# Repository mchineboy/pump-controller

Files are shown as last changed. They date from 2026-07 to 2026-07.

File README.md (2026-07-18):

# Fluid Dispensing Controller

Open-source ESP32 firmware and local web UI for **precision fluid dispensing**
with stepper-driven peristaltic pump(s). Suitable for lab dosing, hydroponics,
coolant metering, photography chemistry, laundry soap, and other applications
where calibrated volume delivery matters.

**Board:** ELEGOO ESP32 Dev Board (ESP32-WROOM-32, CP2102, USB-C)  
**Framework:** PlatformIO + Arduino  
**UI:** HTML / CSS / vanilla JS served from LittleFS  
**License:** [MIT](LICENSE)

## Hardware credit

The 3D-printable peristaltic pump mechanical design is by
**[Maximilian Puschmann](https://www.printables.com/@MaxPuschmann_1657997)**:

- [V2 — Nema 17 Peristaltic Pump on Printables](https://www.printables.com/model/1556845-v2-nema-17-peristaltic-pump-water-pump-measuring-p)
- Local author documentation: [docs/hardware/maximilian-puschmann-nema17-peristaltic-pump-v2.pdf](docs/hardware/maximilian-puschmann-nema17-peristaltic-pump-v2.pdf)

This repository provides the controller firmware, electronics integration, and
web UI around that design. See [docs/HARDWARE.md](docs/HARDWARE.md),
[docs/BOM.md](docs/BOM.md), [docs/WIRING.md](docs/WIRING.md), and
[cad/enclosure/](cad/enclosure/) for dry-side enclosure STEP files
([v1 monolithic](cad/enclosure/v1/), [v2 sectional](cad/enclosure/v2/)).

## Features

- DHCP Wi-Fi (credentials in ignored `include/secrets.h`) with soft-AP fallback
- Local web UI: dispense, calibration, profiles, configuration, diagnostics, hardware
  (includes a dynamic color-coded wiring diagram modal)
- Six generic fluid profiles (Fluid 1–6), renameable, with independent calibration
- **Multi-pump:** 1–3 fluid paths (`pump_count` in Configuration; default **1**)
  - Each profile binds to `pump_1`, `pump_2`, or `pump_3`
  - Sequential motion only (one path at a time); ESTOP stops all paths
  - Shared TMC2209 UART bus (addresses `0b00` / `0b01` / `0b10`)
- STEP/DIR/ENABLE motor control per path (see pin tables below)
- Timed calibration with multi-sample averaging and history
- Configurable speed / acceleration (speed change clears calibration)
- Volume dispense via `steps_per_ml`
- Optional sensors: load cell, temperature, pulse flow; optional closed-loop feedback
- Optional basic auth, event log, config export/import, Factory Reset
- Safe boot: drivers disabled, valves closed, no operation resume
- Durable config in **NVS** (survives firmware and LittleFS uploads)

## Quick start

1. Copy `include/secrets.example.h` to `include/secrets.h` and set Wi-Fi credentials.
2. Connect the board with a data-capable USB-C cable.
3. Build and upload:

```bash
pio run -t upload
pio run -t uploadfs
```

4. Open the DHCP address printed on serial (or fallback AP `PumpController` /
   `pumpsetup` at http://192.168.4.1).

Optional web auth uses `Secrets::kWebUsername` / `kWebPassword` when enabled on
the Configuration page.

### Enabling a second or third pump

1. Wire the extra TMC2209 + NEMA 17 using the pump 2 / pump 3 pins below.
2. Strap UART addresses (`0b01`, `0b10`) on the shared RX/TX lines.
3. In **Configuration → Pumps**, set **Number of installed pumps** to 2 or 3.
4. On **Profiles**, bind each fluid to the correct pump path, then calibrate.

Full detail: [docs/HARDWARE.md](docs/HARDWARE.md#multi-pump--additional-fluid-paths-optional)
and [docs/WIRING.md](docs/WIRING.md).

## Default pins

See [docs/WIRING.md](docs/WIRING.md) for power distribution, TMC2209 connections,
and optional ESTOP / valve / UART / reservoir / sensor wiring.

### Pump 1 (always present)

| Signal | GPIO |
|---|---|
| STEP | 26 |
| DIR | 27 |
| ENABLE | 25 (active low) |
| VALVE  | 33 (optional, disabled by default) |

### Pump 2 (optional, `pump_count` ≥ 2)

| Signal | GPIO |
|---|---|
| STEP | 5 |
| DIR | 13 |
| ENABLE | 14 (active low) |
| VALVE  | 21 (optional) |
| TMC UART address | `0b01` |

### Pump 3 (optional, `pump_count` ≥ 3)

| Signal | GPIO |
|---|---|
| STEP | 22 |
| DIR | 15 (strapping — keep quiet at boot) |
| ENABLE | 2 (active low) |
| VALVE  | 12 (optional; strapping) |
| TMC UART address | `0b10` |

### Shared / optional

| Signal | GPIO |
|---|---|
| ESTOP  | 32 (optional, disabled by default) |
| TMC RX | 16 (optional UART, shared by all drivers) |
| TMC TX | 17 (optional UART, shared by all drivers) |
| RESERVOIR | 34 (optional empty sense) |
| HX711 DT / SCK | 19 / 18 (optional load cell) |
| TEMP | 23 (optional DS18B20) |
| FLOW | 4 (optional pulse) |

## Project layout

```text
src/           firmware
include/       headers
data/          LittleFS web assets
cad/           enclosure STEP / FreeCAD source
docs/          design notes, BOM, hardware credit, wiring
docs/hardware/ pump author documentation (PDF)
.cursor/rules/ agent workflow and documentation rules
```

## Contributing

See [CONTRIBUTING.md](CONTRIBUTING.md) for build setup, scope, and pull request
expectations. Product changes that affect pins, features, storage, or APIs must
update the matching docs in the same PR.

## Notes

- Calibration and hardware settings live in **NVS** and survive `upload` /
  `uploadfs` / OTA. Clear them only via Configuration **Factory Reset** (or a full
  `erase_flash`).
- `pio run -t uploadfs` rewrites LittleFS (web UI). Event logs and on-device
  calibration *history files* on LittleFS are lost; profile calibrations in NVS
  are not.
- ENABLE polarity assumes a typical TMC2209 active-low enable.
- Valve, ESTOP, sensors, and multi-pump paths are off/inactive until enabled in
  Configuration (`pump_count` defaults to 1).
- Size the 12 V supply for **one** NEMA 17 at a time unless you validate
  concurrent motor load (firmware does not run paths concurrently).

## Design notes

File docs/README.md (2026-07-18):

# Documentation

Index of project documentation for the ESP32 fluid dispensing controller.

## Contents

| Document | Description |
|---|---|
| [DESIGN.md](DESIGN.md) | Software design summary: calibration/dispense rules, Configuration vs Diagnostics UI responsibilities, NVS storage, multi-pump model, safety, and phased feature status. |
| [HARDWARE.md](HARDWARE.md) | Mechanical pump credit, electronics overview, optional sensors, **multi-pump pin map** (1–3 paths), safety notes, enclosure CAD links. |
| [BOM.md](BOM.md) | Bill of materials for a complete build; notes how motor/driver/pump parts scale with pump count. |
| [WIRING.md](WIRING.md) | Default ESP32 / TMC2209 pin map for pump 1–3, power distribution, UART addressing, and pre-power safety checks. |
| [hardware/maximilian-puschmann-nema17-peristaltic-pump-v2.pdf](hardware/maximilian-puschmann-nema17-peristaltic-pump-v2.pdf) | Local copy of the upstream peristaltic pump author documentation (print/assembly). |

Dry-side enclosure STEP models live under [`cad/enclosure/`](../cad/enclosure/) (not under `docs/`). The v2 enclosure assumes multi-pump layouts; firmware supports up to **three** sequential paths (`pump_count` 1–3).

**Quick links:** [Multi-pump (HARDWARE)](HARDWARE.md#multi-pump--additional-fluid-paths-optional) · [Pin summary (WIRING)](WIRING.md#pin-summary) · [Flash survival (DESIGN)](DESIGN.md#durable-storage--flash-survival)

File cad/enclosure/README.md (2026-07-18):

# Dry-side electronics enclosure

Two designs share this folder. Prefer **v2** for new builds.

| Version | Layout | When to use |
|---|---|---|
| **[v1](v1/)** — monolithic | Single 120×90 mm box + lid | Simple 1-driver prototypes |
| **[v2](v2/)** — sectional | Controller + driver modules + endcap | 1–6 pumps; each printable part ≤ 200 mm |

Generators write **only** into their own directory and do not delete the other
version’s exports.

## Regenerate

```bash
# v1 monolithic
/Applications/FreeCAD.app/Contents/Resources/bin/freecadcmd \
  cad/enclosure/v1/generate_enclosure_v1.py

# v2 sectional
/Applications/FreeCAD.app/Contents/Resources/bin/freecadcmd \
  cad/enclosure/v2/generate_enclosure_v2.py
```

Pumps do not mount to these enclosures. Keep liquid plumbing physically
separated from the dry-side box. See [docs/HARDWARE.md](../../docs/HARDWARE.md)
and [docs/WIRING.md](../../docs/WIRING.md).

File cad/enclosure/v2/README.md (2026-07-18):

# Enclosure v2 — sectional

Modular dry-side box. Each printable part is ≤ **200 mm** in its longest
dimension. Larger pump counts are built by joining sections.

## Modules

| Part | Role |
|---|---|
| `controller_base/lid` | Half-size breadboard bay, buck bay, barrel jack, USB slot, optional 40 mm fan on lid |
| `driver_x1_base/lid` | One generic TMC2209 + breakout bay |
| `driver_x2_base/lid` | Two generic driver bays |
| `endcap_base/lid` | Three Ø10 mm cable / grommet exits toward the wet side |

Mating: +X tongue into the next module’s −X groove, plus M3 clamp holes at the
joint walls.

## Assembly matrix (N pumps)

Prefer `driver_x2`, remainder `driver_x1`, then always finish with `endcap`:

| N | Sections after controller |
|---|---|
| 1 | x1 + endcap |
| 2 | x2 + endcap |
| 3 | x2 + x1 + endcap |
| 4 | x2 + x2 + endcap |
| 5 | x2 + x2 + x1 + endcap |
| 6 | x2 + x2 + x2 + endcap |

Preview assemblies: `assembly_1pump.step` … `assembly_6pump.step`.

## Design intent

- **Breadboard:** standard half-size 400-point, nominal **82 × 55 × 10 mm**.
- **ESP32** and logic wiring sit on the breadboard.
- **TMC2209** motor VM / coil current uses rated breakout boards in driver bays.
- **Buck converter:** generic ~40 × 20 × 10 mm bay near the barrel jack.
- Concurrent pumps: space for 1–6 drivers; design assumption **up to 3 concurrent**.
- Corner bosses: **M3 heat-set insert** pilots (Ø4.0 mm).
- Controller lid: optional **40 mm fan** (32 mm screw pitch).

## Envelope (per module)

Widths and heights are shared: **95 × ~53 mm** (base 50 + lid 3). Lengths are
printed by the generator at run time.

## Files

| File | Description |
|---|---|
| `generate_enclosure_v2.py` | Parametric generator |
| `enclosure_sectional.FCStd` | FreeCAD document |
| `controller_*`, `driver_*`, `endcap_*` | Module STEP exports |
| `assembly_*pump.step` | Preview assemblies |

## Regenerate

```bash
/Applications/FreeCAD.app/Contents/Resources/bin/freecadcmd \
  cad/enclosure/v2/generate_enclosure_v2.py
```

Writes only into `cad/enclosure/v2/` — does not modify [v1](../v1/) exports.

## Print / assembly notes

- PETG recommended.
- Install M3 heat-set inserts in base bosses; M3×8–12 mm lid screws.
- Confirm barrel-jack panel diameter (`BARREL_D`).
- Fit rubber grommets in endcap cable exits.
- Revise `DRIVER_BAY_*` once the exact breakout board is chosen.

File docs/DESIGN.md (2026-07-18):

# Software Design Summary

Source: project software design document (2026-07-18).

## Core decisions

1. **Calibration:** timed dispense (default 1000 ms) → user enters measured mL → store `steps_per_ml`.
2. **Dispense:** `target_steps = volume_ml * steps_per_ml` (step-count based, not wall-clock only).
3. **Speed rule:** calibration speed must equal dispense speed.
4. **Web client:** HTML + CSS + vanilla JS + ES modules + `fetch` + SSE. No React/Vue/etc.
5. **Storage:** Preferences/NVS for settings **and** fluid profiles/calibration;
   LittleFS for web assets, optional calibration history, and event logs.
6. **Safety:** safe boot, no auto-resume after power loss, software stop, optional ESTOP later.

## Implemented

### Phase 1–2
- Six generic fluid profiles (Fluid 1–6), renameable per use case
- Repeated calibration samples with averaging / CV warning (>3%)
- Calibration history per profile
- Configurable speed and acceleration
- Optional local basic auth (`admin` / `secrets.h`)
- Event logging
- Configuration export / import

### Phase 3 (complete)
- Optional valve pre-open / post-close, anti-drip reverse
- TMC2209 UART config + diagnostics
- Physical ESTOP
- Reservoir empty sensor (warn/block/fault)

### Phase 4 (in progress)
Tracked on GitHub milestone **Phase 4**, in design-doc order:
1. Load-cell verification (HX711) — done
2. Temperature monitoring — done
3. Flow sensor — done
4. Closed-loop dispensing — done
5. Multi-pump support — done (up to three paths, sequential motion; `pump_count` default 1)
6. Automated mixing jobs
7. Recipe engine (use-case agnostic)

Product branding is use-case agnostic: **Fluid Dispensing Controller**.

## Multi-pump model

- **Paths:** `pump_1` … `pump_3` (compile-time pins in `Config.h` / `platformio.ini`).
- **Setting:** `GlobalSettings.pumpCount` (NVS), default `1`. Configuration UI sets 1–3.
- **Binding:** each `FluidProfile` has `pump_id`; dispense/calibrate select that path’s STEP/DIR/EN (+ optional valve).
- **Motion:** one global busy operation — no concurrent STEP generation in this cut.
- **TMC UART:** shared RX/TX; per-driver address `0b00` / `0b01` / `0b10`.
- **Safety:** ESTOP and safe-output paths stop/disable **all** configured pumps.

Pin tables and strapping notes: [HARDWARE.md](HARDWARE.md), [WIRING.md](WIRING.md), root [README.md](../README.md).

## Durable storage / flash survival

| Data | Location | Survives `upload` | Survives `uploadfs` | Survives OTA app | Cleared by |
|---|---|---|---|---|---|
| Hardware settings | NVS `pump_settings` | Yes | Yes | Yes | Factory Reset / `erase_flash` |
| Profiles + calibration | NVS `pump_prof` | Yes | Yes | Yes | Factory Reset / `erase_flash` |
| Web UI assets | LittleFS | Yes | Replaced | Yes | `uploadfs` |
| Event log / cal history | LittleFS | Yes | Lost | Yes | `uploadfs` / Factory Reset |

Firmware never erases NVS on boot or upgrade. Explicit **Factory Reset**
(`POST /api/factory-reset` with `{"confirm":"FACTORY_RESET"}`) clears NVS
namespaces and reseeds defaults, then reboots.

## Web UI responsibilities

- **Configuration:** durable device, pump, safety, sensor, feedback, and
  motor-driver settings; scale setup; Factory Reset.
- **Diagnostics:** live hardware readings, fault simulation/acknowledgement,
  flow-session reset, and event log.
- **Hardware:** read-only pin-map reference and a color-coded SVG wiring
  diagram modal driven by the active pump count and enabled options.

Configuration uses outcome-oriented labels and keeps electrical details behind
progressive disclosure. Diagnostics does not mutate durable hardware settings.

## Board

ELEGOO ESP32 Dev Board · ESP32-WROOM-32 · CP2102 · USB-C · PlatformIO `esp32dev`.

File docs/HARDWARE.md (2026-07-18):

# Hardware

## Primary credit — peristaltic pump mechanical design

The printable peristaltic pump (housing, tube-pressure part, lid, and bearing
holder/rotor) is **not** an original design of this repository.

**Primary designer:** [Maximilian Puschmann](https://www.printables.com/@MaxPuschmann_1657997)
**Model:** [V2 — Nema 17 Peristaltic Pump / Water Pump / Measuring Pump](https://www.printables.com/model/1556845-v2-nema-17-peristaltic-pump-water-pump-measuring-p)
**Local copy of the author’s documentation:**
[hardware/maximilian-puschmann-nema17-peristaltic-pump-v2.pdf](hardware/maximilian-puschmann-nema17-peristaltic-pump-v2.pdf)

Download the STEP/STL files and follow print/assembly guidance from the
Printables page. Adjust the bearing-holder fit for your printer before pressing
on 608 bearings.

This project contributes the ESP32 controller firmware, electronics integration,
optional valve path, calibration/dispense software, and local web UI around that
mechanical design.

## Electronics overview

| Role | Part |
|---|---|
| Controller | ESP32 development board (Wi-Fi, USB programming) |
| Motor | STEPPERONLINE NEMA 17 bipolar stepper (1.5 A/phase) |
| Driver | BIGTREETECH TMC2209 V1.3 UART StepStick |
| Motor supply | 12 V regulated DC supply |
| Logic supply | 5 V buck converter feeding ESP32 5V/VIN |

Full part list: [BOM.md](BOM.md).
Wiring diagrams and connection tables: [WIRING.md](WIRING.md).
On the device, open **Hardware → View wiring diagram** (also linked from
**Configuration → Pumps**) for a color-coded SVG of the active pump count and
enabled options.
Dry-side enclosure STEP models: [../cad/enclosure/](../cad/enclosure/)
([v1 monolithic](../cad/enclosure/v1/), [v2 sectional](../cad/enclosure/v2/)).

## Safety notes

- Verify the 5 V buck output with a multimeter before connecting the ESP32.
- Keep liquid plumbing physically separated from electronics.
- Do not drive a piezoelectric valve directly from an ESP32 GPIO; use a matched
  valve driver.
- Place an inline fuse near the 12 V power-entry point when building a permanent
  enclosure.

## Emergency stop (optional)

Default pin: **GPIO 32** (`PUMP_ESTOP_PIN`), active-low with ESP32 internal pull-up.

Recommended wiring:

- Use a normally-open (NO) momentary or maintained ESTOP that connects GPIO 32
  to GND when pressed/latched.
- Keep the switch on a short, dedicated cable; do not share with motor power
  returns in a way that injects noise onto the sense line.
- Enable “Use the wired emergency-stop input” in Configuration before relying on
  the switch. When enabled, ESTOP is polled in the firmware loop (not via HTTP).
- On assert: step pulses stop, valve closes, driver disables, system enters
  fault. Clear the switch, then acknowledge the fault in the UI before starting
  another operation.

## TMC2209 UART (optional)

Default pins: **RX GPIO 16**, **TX GPIO 17** (`PUMP_TMC_RX_PIN` / `PUMP_TMC_TX_PIN`).
Baud: 115200. Driver address: `0b00` (MS1/MS2 low on BIGTREETECH V1.3).

Wiring notes:

- Connect ESP32 TX → TMC PDN_UART (through the board’s UART path; do not leave
  PDN_UART floating if UART mode is intended).
- Connect ESP32 RX ← TMC UART TX / PDN_UART sense path per the StepStick silkscreen.
- Keep STEP/DIR/ENABLE wired regardless; UART only configures current,
  microsteps, and StealthChop. Motion remains STEP/DIR.
- Sense resistor assumed **0.11 Ω** (standard on BTT TMC2209 V1.3).
- Open Configuration → Advanced motor-driver settings, enable UART, and set
  run/hold current and microsteps.
  On miswire or no response, boot continues in STEP/DIR-only mode and logs
  `tmc_uart_warning` / `tmc_uart_no_response`.

When UART is ready, firmware polls `DRV_STATUS` about every 100 ms. Overtemperature
or short-circuit flags raise `motor_driver_fault`, stop motion, and close the valve.
Open-load is only treated as a fault while coils are driven. Acknowledge after the
condition clears (Diagnostics includes a simulate-fault control for testing without
hardware).

## Reservoir level sensor (optional)

Default pin: **GPIO 34** (`PUMP_RESERVOIR_PIN`). This pin is input-only and has no
internal pull-up; use an external pull-up (e.g. 10 kΩ to 3.3 V) with a
normally-open float or optical empty switch to GND for active-low empty.

Recommended wiring:

- Float switch or optical liquid sensor that asserts empty when the reservoir is
  low/dry.
- Default polarity: empty = LOW (Configuration labels this “Sensor connects the
  input to ground when empty”). Invert if your sensor is active-high.
- Policy options: **warn** (status only), **block** (refuse new dispense/calibrate),
  **fault** (also stop an in-progress operation with `reservoir_empty`).
- With the sensor disabled, dispense behavior is unchanged.

## Load cell / HX711 (optional)

Default pins: **DT GPIO 19**, **SCK GPIO 18** (`PUMP_LOADCELL_DT_PIN` /
`PUMP_LOADCELL_SCK_PIN`). Channel A, gain 128.

Recommended parts:

- HX711 amplifier module (5 V or 3.3 V logic-compatible with ESP32 levels)
- Strain-gauge load cell sized for the expected container + fluid mass (e.g.
  1–5 kg for typical beaker verification)

Wiring:

- HX711 DT → GPIO 19, SCK → GPIO 18, VCC/GND per module rating
- Excitation and sense to the load cell per HX711 silkscreen (E+/E−, A+/A−)

Usage:

- Enable and calibrate the scale in Configuration, then set zero with the empty
  vessel on the cell
- Place a known mass and **Calibrate** (stores scale factor + offset in NVS)
- Status shows grams and optional mL via fluid density (g/mL)
- Miswire/timeout does not brick boot; logs `loadcell_warning`
- Does not alter dispense control yet (closed-loop is a later Phase 4 issue)

## Temperature sensor (optional)

Default pin: **GPIO 23** (`PUMP_TEMP_PIN`), 1-Wire **DS18B20**.

Wiring:

- DS18B20 data → GPIO 23 with **4.7 kΩ** pull-up to 3.3 V
- VDD to 3.3 V (or parasite power per datasheet), GND to GND

Usage:

- Enable in Configuration; optional warn-low / warn-high thresholds (°C)
- Status shows live °C; threshold crossings log `temp_threshold` (warn only, no fault)
- Absent sensor does not brick boot (`temp_no_device` / `temp_warning`)

## Flow sensor (optional)

Default pin: **GPIO 4** (`PUMP_FLOW_PIN`), active-low pulse with internal pull-up.

Recommended: hall-effect turbine flow meter with open-collector/NPN pulse output
(common YF-S201-class sensors; set pulses-per-liter from the datasheet K-factor).

Wiring:

- Pulse → GPIO 4, GND shared; supply the sensor at its rated voltage (often 5 V)
  with level-safe signaling to the ESP32

Usage:

- Enable in Configuration and set pulses/liter
- Status shows mL/min and cumulative mL; **Reset cumulative** clears the session
  total (`POST /api/flow/reset`)
- Does not alter dispense control yet (closed-loop is #20)

## Dispense feedback / closed-loop (optional)

Configuration section **Volume accuracy**:

- `open_loop` (default): step-count only
- `verify_after`: run open-loop, then compare load-cell or flow volume to request
- `stop_on_feedback`: stop motor when feedback volume reaches ~98% of request

Source: `auto` (load cell if ready, else flow), `load_cell`, or `flow`. Density
(g/mL) converts load-cell mass to mL. Out-of-tolerance can **warn** or **fault**
(`volume_verification_failed`). Sensor loss during feedback modes raises
`feedback_sensor_lost`.

## Multi-pump / additional fluid paths (optional)

Default is **one path** (`pump_count = 1`), identical to prior single-pump builds.

Set **Number of installed pumps = 2 or 3** in Configuration to activate
additional STEP/DIR/ENABLE paths. Bind each fluid profile to `pump_1`,
`pump_2`, or `pump_3` on the Profiles page.

| Path | STEP | DIR | ENABLE | Optional valve | TMC UART address |
|---|---|-----|---|---|---|
| `pump_1` | GPIO 26 | GPIO 27 | GPIO 25 | GPIO 33 | `0b00` (MS1/MS2 low) |
| `pump_2` | GPIO 5 | GPIO 13 | GPIO 14 | GPIO 21 | `0b01` |
| `pump_3` | GPIO 22 | GPIO 15 | GPIO 2 | GPIO 12 | `0b10` |

All TMC2209 drivers share UART pins RX 16 / TX 17; address via MS1/MS2.
Motion is **sequential**: only one path runs at a time. ESTOP stops all paths.

**Strapping:** GPIO 15 (pump 3 DIR) and GPIO 12 (pump 3 valve) are ESP32 boot
strapping pins. Keep external loads from forcing bad levels at reset; firmware
drives safe idle levels after boot.

See [WIRING.md](WIRING.md) pin summary for the full map.

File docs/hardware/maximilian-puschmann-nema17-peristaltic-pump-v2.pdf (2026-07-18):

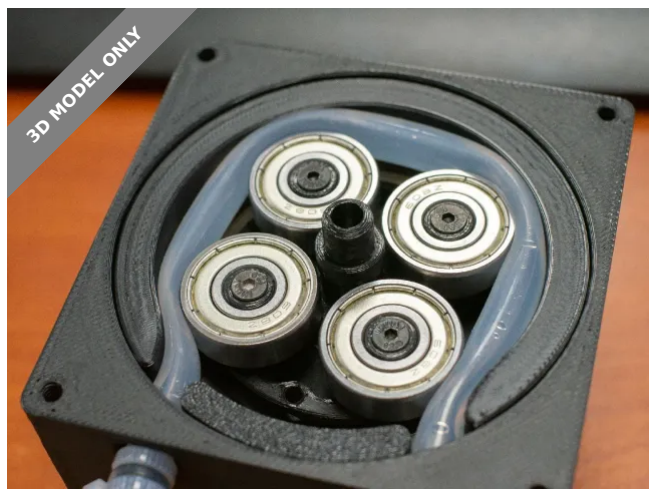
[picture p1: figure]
3D MODEL ONLY

## Summary

V2 Peristaltic Pump. Allows you to pump specific fluids without ever touching anything besides the tube itself.

Hobby & Makers (https://printables.com/model?categoryId=48) > Electronics (https://printables.com/model?categoryId=52)

Peristaltic Pump (NEMA 17)

This is a compact, fully 3D-printable peristaltic pump designed to be driven by a NEMA 17 stepper motor.
The pump uses standard 608 bearings and soft tubing, making it easy to build with commonly available parts.

Peristaltic pumps are ideal for liquid handling because the fluid only contacts the tubing. This makes the design suitable for water, coolants, and other non-aggressive liquids.
⚙ How it works

The stepper motor rotates the bearing rotor.
As the bearings roll over the tubing, they compress it sequentially, pushing the liquid forward.
This design is self-priming and naturally prevents backflow without additional valves.

Maximilian Puschmann (https://printables.com/@MaxPuschmann_1657997)

## V2 -- Nema 17 Peristaltic Pump / Water Pump / measuring Pump

VIEW IN BROWSER (https://printables.com/model/1556845-v2-nema-17-peristaltic-pump-water-pump-measuring-p)

updated 25. 1. 2026 | published 25. 1. 2026

The flow rate can be precisely controlled by adjusting the stepper motor speed.
Bill of Materials

Hardware

5× 608 bearings
1× NEMA 17 stepper motor
4× M3 screws (16 mm) – motor mounting
4× M3 screws (15–30 mm) – housing assembly

Tubing

### 8 mm soft tubing (silicone recommended)

Slightly smaller or larger tubing also works if the spacer is adjusted accordingly.

Electronics

Stepper motor driver (A4988, DRV8825, etc.) Microcontroller (Arduino or similar)
Suitable power supply
Print Settings

Bearing holder / rotor

Infill: 60%
Layer height: 0.2 mm
Material: PLA / PETG / ABS

Housing

Infill: 15%
Layer height: 0.2 mm

Supports are not required when printed in the recommended orientation.
Assembly Notes

Press the 608 bearings firmly into the rotor (no glue required) Insert the tubing into the housing before final assembly
Lightly gluing the tubing is recommended to prevent slipping during operation
Mount the pump assembly to the stepper motor using the 16 mm M3 screws
Test the pump at low speed before increasing RPM

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
## Model files

⚠ Important Notes

Use soft tubing only – hard tubing will not work
Not designed for high-pressure applications
Chemical compatibility depends on the tubing material used
Updates

09.04.24 – Improved bearing press-fit based on community feedback 10.01.26 – Version 2 files uploaded
19.01.26 – Previously missing file added

## This remix is based on

V1 -- Nema 17 Peristaltic Pump / Water Pump / measuring Pump (https://printables.com/model/818373-v1-nema-17-peristaltic-pump-water-pump-measuring-p)
by Maximilian Puschmann (https://printables.com/@MaxPuschmann_1657997)

•
•
•

•
•
•

main-housing.stl

tube-pressure-part.stl

deckel.stl

bearing-place-holder.stl

## License

This work is licensed under a
Creative Commons (4.0 International License)

Attribution-ShareAlike (http://creativecommons.org/licenses/by-sa/4.0/)

✖ | Sharing without ATTRIBUTION
✔ | Remix Culture allowed
✔ | Commercial Use
✔ | Free Cultural Works
✔ | Meets Open Definition

tube-preasure-part.step

v2-main-housing.step

v2-lid.step

peristaltic-pump-v2-finished-model-not-for-printing.step

bearing-place-holder.step

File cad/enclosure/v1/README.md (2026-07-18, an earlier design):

# Enclosure v1 — monolithic

Single-box dry-side enclosure for ESP32 + TMC2209 on solderless carriers.
Superseded for multi-pump work by [v2](../v2/); kept for simple prototypes and
CAD reference.

## Files

| File | Description |
|---|---|
| `enclosure_base.step` | Box with board zones, barrel jack, cable exits, USB, vents |
| `enclosure_lid.step` | Lid with lip, M3 holes, TMC vents |
| `enclosure_assembly.step` | Base + lid preview |
| `enclosure_monolithic.FCStd` | FreeCAD document |
| `generate_enclosure_v1.py` | Parametric generator |

## Envelope

120 × 90 × ~45 mm (base 42 + lid 3). Wall / floor 2.5 mm.

## Regenerate

```bash
/Applications/FreeCAD.app/Contents/Resources/bin/freecadcmd \
  cad/enclosure/v1/generate_enclosure_v1.py
```

Writes only into `cad/enclosure/v1/`.

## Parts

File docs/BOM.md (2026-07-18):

# Bill of Materials

Parts for a complete precision fluid dispensing build using Maximilian
Puschmann’s NEMA 17 peristaltic pump and this ESP32 controller.

| Category | Item | Description / Specification | Qty | Required | Notes |
|---|---|---|-----|---|---|
| Controller | ESP32 development board | ESP32 with Wi-Fi, USB programming, 5V/VIN input, and sufficient GPIO | 1 | Yes | Exact board model not yet specified; scaffold targets ELEGOO ESP32 Dev Board (ESP32-WROOM-32, CP2102, USB-C) |
| Motor | Stepper motor | STEPPERONLINE NEMA 17 bipolar stepper, 1.5 A/phase, 42 N·cm, 42×42×38 mm, 1.8°, 4-wire, 1 m cable | 1 | Yes | Directly drives the peristaltic pump rotor |
| Motor Driver | Stepper driver | BIGTREETECH TMC2209 V1.3 UART StepStick, 2.8 A peak | 1 | Yes | Two-pack may be purchased; one module is required and one can be retained as a spare |
| Power | 12V power adapter | ALITOVE regulated 12 V DC, 3 A, 36 W, 100–240 V AC input, center-positive 5.5×2.1/2.5 mm plug | 1 | Yes | Powers the stepper driver and feeds the 5 V buck converter |
| Power | 5V buck converter | Fixed-output DC-DC step-down module, 5–30 V input to regulated 5 V output, rated up to 3 A | 1 | Yes | Feeds the ESP32 5V/VIN input; verify output with a multimeter before connection |
| Power | Barrel jack adapter | Female 5.5×2.1/2.5 mm barrel-jack to screw-terminal adapter | 1 | Recommended | Convenient connection from the power adapter to project wiring |
| Power | Motor supply capacitor | 220–470 µF, 25 V electrolytic capacitor | 1 | Recommended | Install close to TMC2209 VMOT and GND |
| Pump | 608 bearings | Standard 608 bearing, nominal 8 mm bore × 22 mm OD × 7 mm width | 5 | Yes | Press onto the printed bearing-holder posts after adjusting the STEP model for fit |
| Pump | Tubing | Soft 8 mm OD tubing; silicone recommended by the pump design | As needed | Yes | Use tubing chemically compatible with the target fluid; dedicate a line per fluid when cross-contamination matters |
| Pump | Motor mounting screws | M3 × 16 mm screws | 4 | Yes | Mount pump housing to NEMA 17 motor |
| Pump | Housing assembly screws | M3 screws, 15–30 mm length | 4 | Yes | Final length depends on the printed housing and lid |
| Pump | Printed pump components | Main housing, tube-pressure part, lid, and bearing holder/rotor from [Puschmann’s design](HARDWARE.md) | 1 set | Yes | PETG recommended for the functional pump parts |
| Valve | Piezoelectric valve | Normally closed, chemically compatible fluid valve sized for the selected tubing and required flow | 1 | Optional | Sharper cutoff, reduced dripping, improved small-volume control |
| Valve | Valve driver | Driver/interface matched to the selected piezoelectric valve voltage and waveform requirements | 1 | Optional | Do not drive a piezoelectric valve directly from an ESP32 GPIO |
| Wiring | Hookup wire and connectors | Wire, ferrules or crimp terminals, and connectors suitable for 12 V power, motor phases, and low-voltage control | 1 set | Yes | Keep motor wiring separated from ESP32 signal wiring where practical |
| Thermal | TMC2209 heatsink | Small adhesive heatsink appropriate for the StepStick module | 1 | Recommended | Often included with the BIGTREETECH driver package |
| Safety | Fuse | Inline fuse and holder sized for the 12 V input, approximately 3 A | 1 | Recommended | Place near the 12 V power-entry point |
| Safety | Emergency stop switch | Normally-open switch or latching ESTOP that connects GPIO 32 to GND when asserted | 1 | Optional | Enable in Configuration; see [HARDWARE.md](HARDWARE.md) |
| Sensing | Load cell | Strain-gauge load cell, typically 1–5 kg capacity, matched mount for vessel | 1 | Optional | Phase 4 verification; pair with HX711 |
| Sensing | HX711 amplifier | HX711 load-cell ADC module, ESP32-compatible logic levels | 1 | Optional | DT GPIO 19, SCK GPIO 18 by default |
| Sensing | Temperature sensor | DS18B20 1-Wire digital thermometer | 1 | Optional | GPIO 23 with 4.7 kΩ pull-up to 3.3 V |
| Sensing | Flow sensor | Hall-effect turbine / pulse flow meter (e.g. YF-S201 class) | 1 | Optional | Pulse to GPIO 4; set pulses/liter from datasheet |
| Enclosure | Controller enclosure | Ventilated enclosure for ESP32, driver, buck converter, terminals, and optional valve driver | 1 | Recommended | Keep liquid plumbing physically separated from electronics |

## Multi-pump builds (2–3 paths)

Firmware supports up to **three** sequential pump paths (`pump_count` in Configuration).
For each **additional** path beyond the first, plan on:

| Item | Qty per extra path | Notes |
|---|---|---|
| NEMA 17 stepper | +1 | Same spec as primary motor |
| TMC2209 StepStick | +1 | Unique UART address (`0b01`, `0b10`); share RX/TX with pump 1 |
| Printed pump set + bearings + tubing | +1 set | Dedicate tubing per fluid |
| Motor supply capacitor | +1 recommended | Close to each driver’s VMOT |
| Optional valve + driver | +1 | Per-path valve GPIOs: 33 / 21 / 12 |

**Power:** the stock 12 V / 3 A adapter is sized for **one** motor running at a time
(firmware does not run paths concurrently). Upsize the PSU only if you later enable
true concurrent motion or other heavy loads.

Pin map: [HARDWARE.md](HARDWARE.md#multi-pump--additional-fluid-paths-optional),
[WIRING.md](WIRING.md).

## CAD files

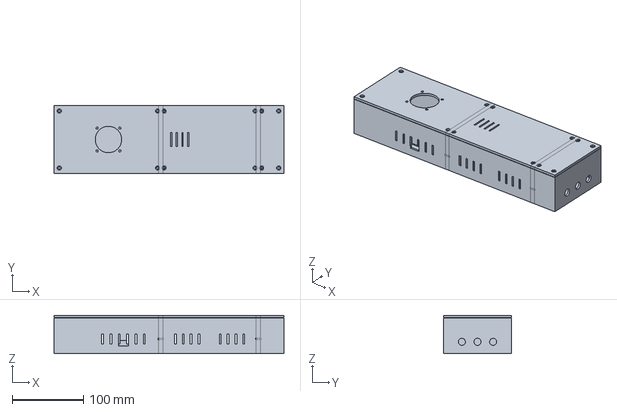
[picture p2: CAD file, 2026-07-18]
cad/enclosure/v2/assembly_2pump.step
323.0 x 95.0 x 53.5 mm

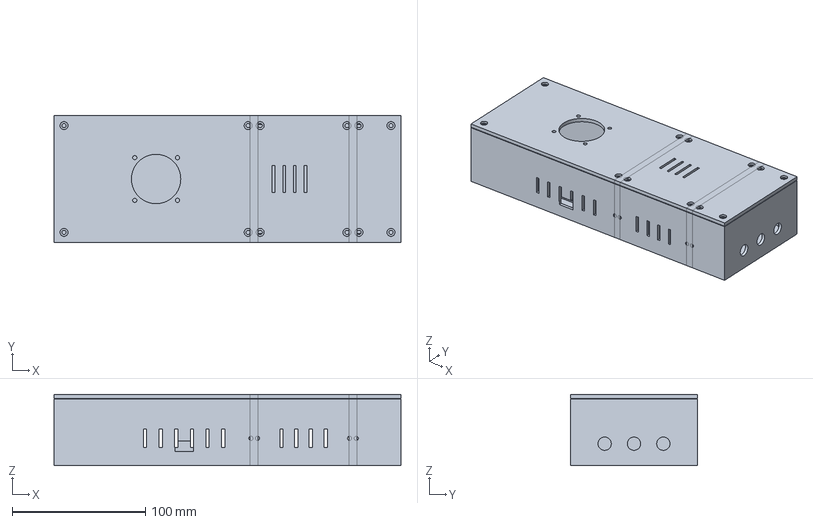
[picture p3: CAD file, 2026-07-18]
cad/enclosure/v2/assembly_1pump.step
260.0 x 95.0 x 53.5 mm

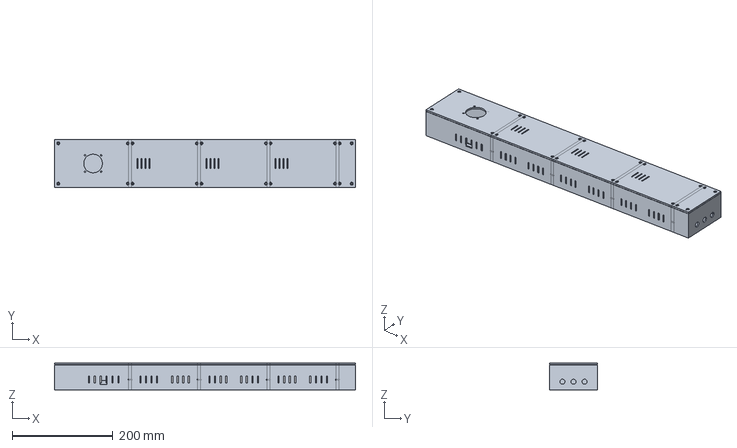
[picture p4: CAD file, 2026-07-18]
cad/enclosure/v2/assembly_6pump.step
597.0 x 95.0 x 53.5 mm

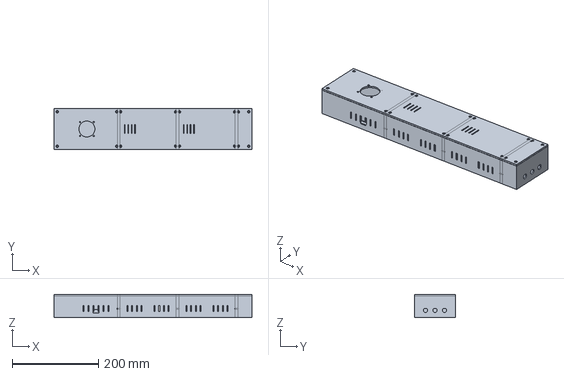
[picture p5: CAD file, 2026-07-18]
cad/enclosure/v2/assembly_4pump.step
460.0 x 95.0 x 53.5 mm

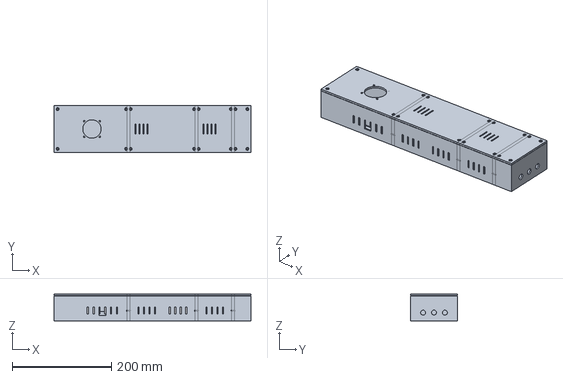
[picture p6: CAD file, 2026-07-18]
cad/enclosure/v2/assembly_3pump.step
397.0 x 95.0 x 53.5 mm

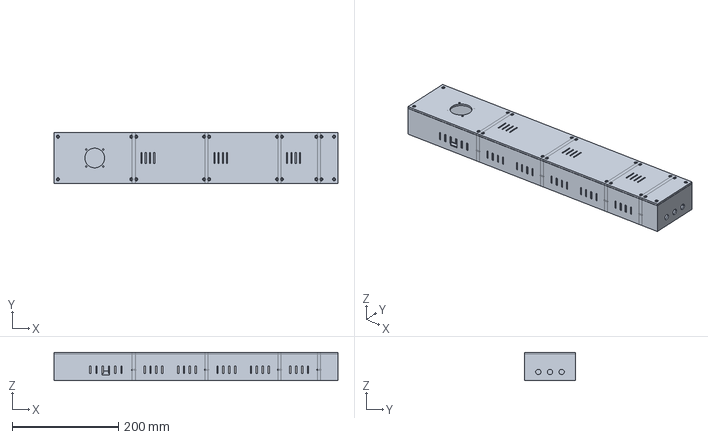
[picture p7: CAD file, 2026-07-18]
cad/enclosure/v2/assembly_5pump.step
534.0 x 95.0 x 53.5 mm

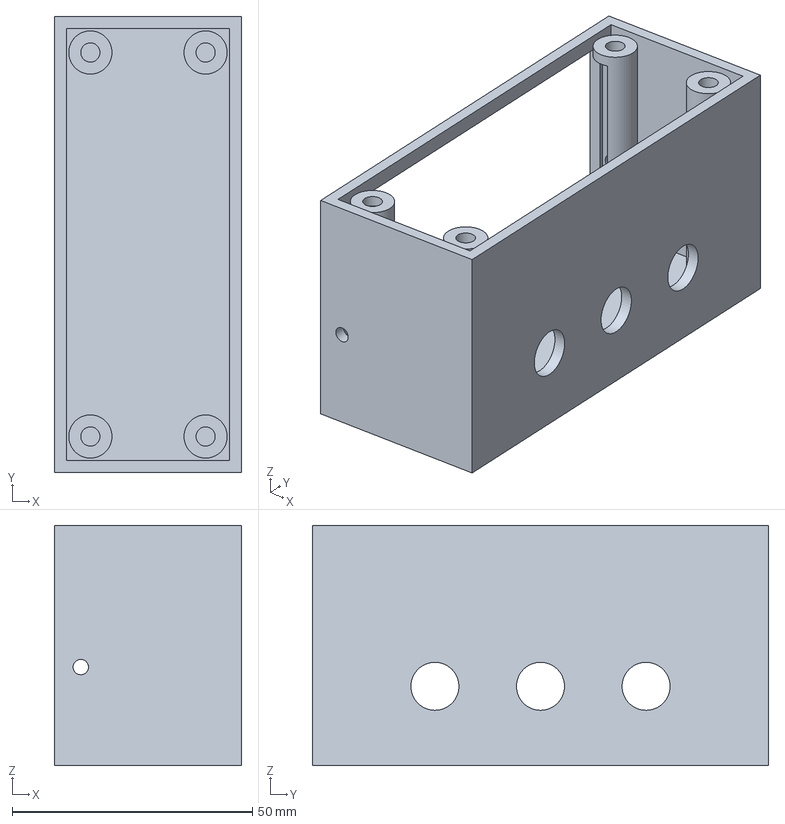
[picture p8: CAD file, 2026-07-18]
cad/enclosure/v2/endcap_base.step
39.0 x 95.0 x 50.0 mm

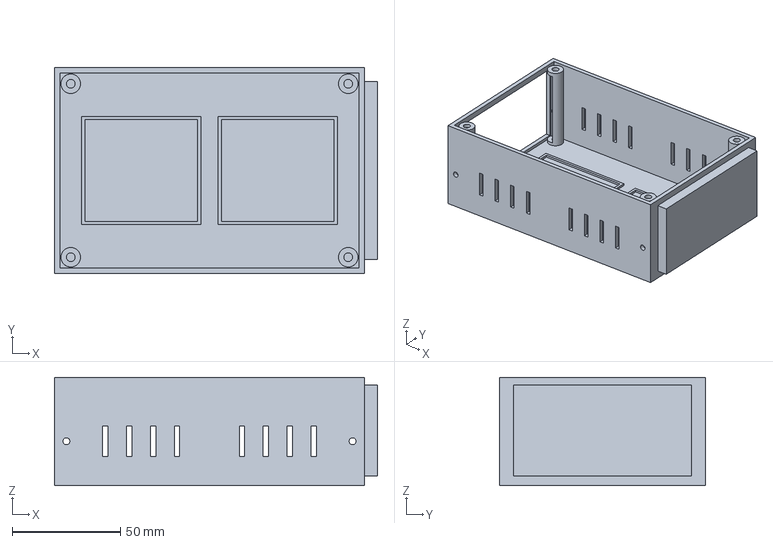
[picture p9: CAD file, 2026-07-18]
cad/enclosure/v2/driver_x2_base.step
149.0 x 95.0 x 50.0 mm

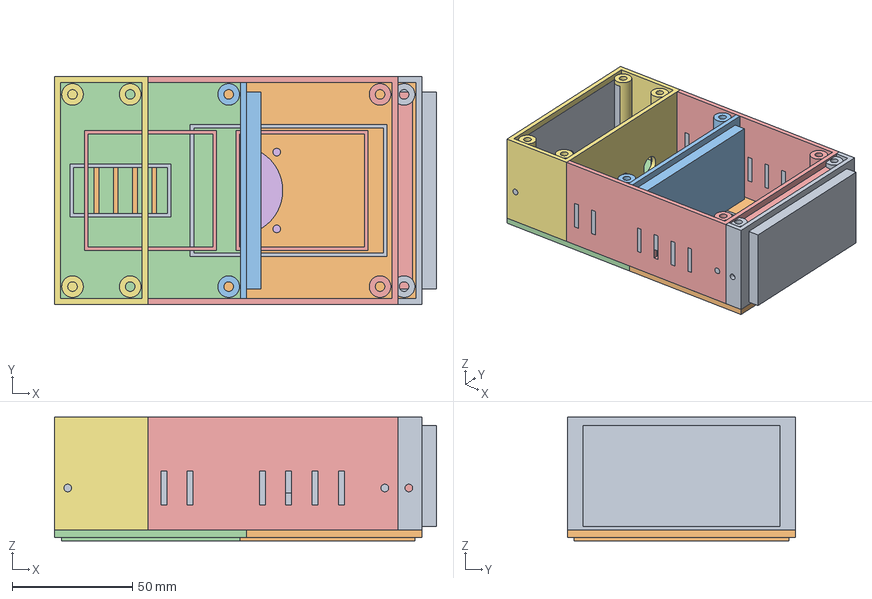
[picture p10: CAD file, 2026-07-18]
cad/enclosure/v2/enclosure_sectional.FCStd
159.0 x 95.0 x 51.5 mm
controller_base
controller_lid
driver_x1_base
driver_x1_lid
driver_x2_base
driver_x2_lid
endcap_base
endcap_lid

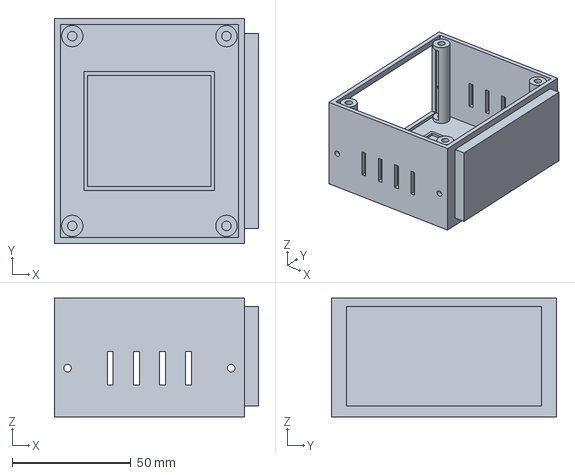
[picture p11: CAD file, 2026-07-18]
cad/enclosure/v2/driver_x1_base.step
86.0 x 95.0 x 50.0 mm

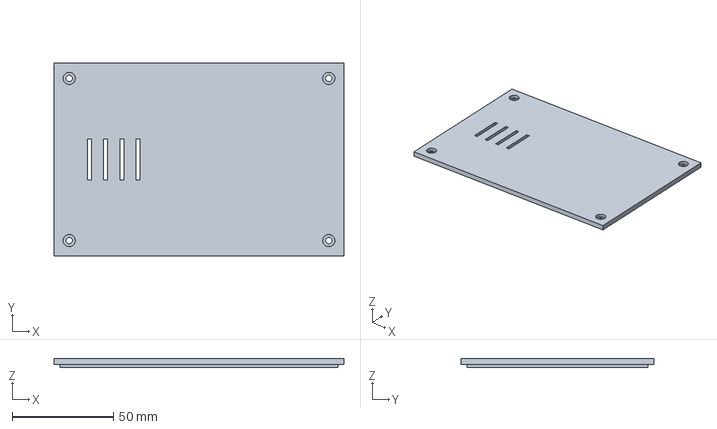
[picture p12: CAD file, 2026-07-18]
cad/enclosure/v2/driver_x2_lid.step
143.0 x 95.0 x 4.50 mm

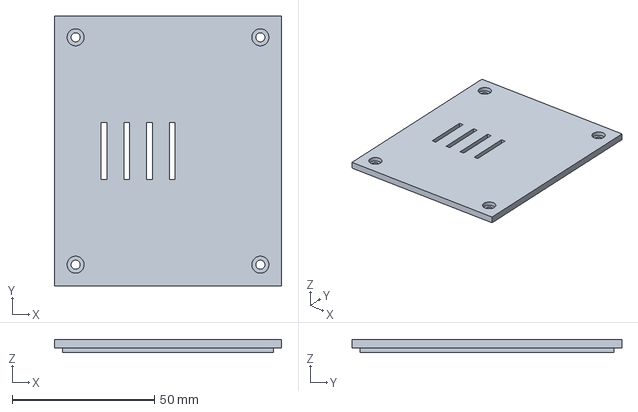
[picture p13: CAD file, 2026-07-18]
cad/enclosure/v2/driver_x1_lid.step
80.0 x 95.0 x 4.50 mm

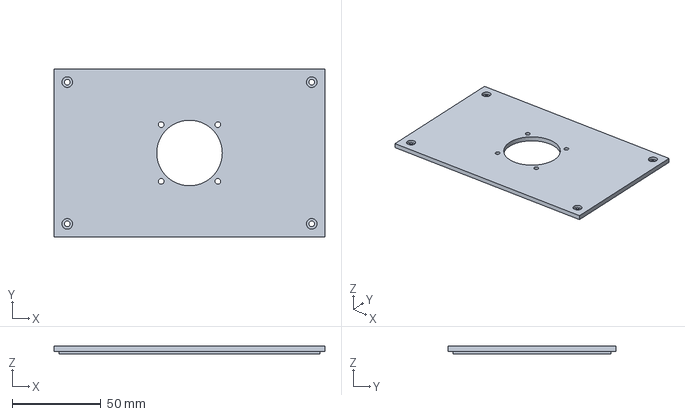
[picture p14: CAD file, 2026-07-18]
cad/enclosure/v2/controller_lid.step
153.0 x 95.0 x 4.50 mm

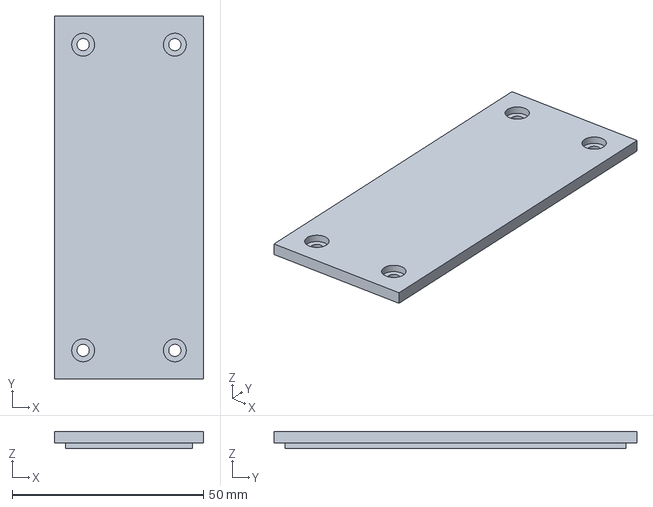
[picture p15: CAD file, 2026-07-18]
cad/enclosure/v2/endcap_lid.step
39.0 x 95.0 x 4.50 mm

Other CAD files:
cad/enclosure/v2/controller_base.step
cad/enclosure/v1/enclosure_assembly.step
cad/enclosure/v1/enclosure_monolithic.FCStd
cad/enclosure/v1/enclosure_base.step
cad/enclosure/v1/enclosure_lid.step

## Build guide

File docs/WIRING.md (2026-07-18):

# Wiring

Default pin map for the ELEGOO ESP32 Dev Board (`esp32dev`) and a BIGTREETECH
TMC2209 V1.3 StepStick. Override pins in `platformio.ini` if your board differs.

The on-device **Hardware** and **Configuration** pages include a **View wiring
diagram** modal that draws the active pump count, valves, UART, ESTOP, and
enabled sensors with color-coded signal lines. Treat that diagram as a live
summary; this document remains the authoritative connection and safety guide.

**Related:** [HARDWARE.md](HARDWARE.md) · [BOM.md](BOM.md)

## Safety before you power on

1. Verify the buck converter outputs **5.0 V ±0.1 V** before connecting ESP32
   `5V`/`VIN`.
2. Tie all grounds together (12 V supply, buck, TMC2209, ESP32).
3. Do **not** feed 12 V into the ESP32 `5V`/`VIN` pin.
4. Do **not** drive a piezoelectric valve from an ESP32 GPIO; use a matched
   valve driver.
5. Fit the motor supply capacitor close to TMC2209 `VMOT` and `GND`.
6. Use an inline ~3 A fuse on the 12 V input for permanent builds.

## System overview

```mermaid
flowchart LR
  subgraph mains [Mains]
    PSU["12 V DC supply<br/>3 A regulated"]
  end

  subgraph power [Power distribution]
    FUSE["Inline fuse ~3 A"]
    CAP["220–470 µF / 25 V<br/>at VMOT"]
    BUCK["5 V buck converter"]
  end

  subgraph logic [Logic]
    ESP["ESP32 Dev Board<br/>5V/VIN"]
  end

  subgraph motion [Motion]
    TMC["TMC2209 V1.3"]
    MOTOR["NEMA 17 stepper"]
    PUMP["Peristaltic pump<br/>Puschmann V2"]
  end

  PSU --> FUSE
  FUSE --> CAP
  CAP --> TMC
  FUSE --> BUCK
  BUCK -->|"5 V"| ESP
  ESP -->|"STEP DIR EN<br/>optional UART"| TMC
  TMC --> MOTOR
  MOTOR --> PUMP
```

## Required connections

### Power

| From | To | Notes |
|---|-----|---|
| 12 V adapter + | Fuse input | Center-positive barrel jack typical |
| Fuse output | Buck `VIN+`, TMC `VMOT`, capacitor + | Common 12 V rail |
| 12 V adapter − | Buck `VIN−`/`GND`, TMC `GND`, capacitor −, ESP32 `GND` | Common ground |
| Buck `VOUT+` (5 V) | ESP32 `5V` or `VIN` | Confirm 5 V before connecting |
| Buck `VOUT−` | ESP32 `GND` | Same ground as above |
| ESP32 `3V3` | TMC `VIO` | Logic reference for STEP/DIR/EN/UART (3.3 V) |

Capacitor polarity matters: positive to `VMOT`, negative to `GND`, leads as short
as practical.

### Stepper driver control (required)

| ESP32 GPIO | TMC2209 signal | Notes |
|---|---|---|
| **26** | `STEP` | Step pulses |
| **27** | `DIR` | Direction |
| **25** | `EN` / `ENABLE` | **Active low** — HIGH at boot = driver disabled |
| `GND` | `GND` | Must share ground with motor supply |

Leave TMC `MS1`/`MS2` as needed for UART address `0b00` (both low on BTT V1.3
defaults) when using UART later.

### Motor phases

| TMC2209 | NEMA 17 (typical 4-wire) |
|---|---|
| `A1` / `A2` | Coil A (one pair) |
| `B1` / `B2` | Coil B (other pair) |

Identify coil pairs with a multimeter (continuity within a pair). STEPPERONLINE
leads are often black/green and red/blue, but **verify against your motor
datasheet**. If the pump runs the wrong way, invert direction in the UI or swap
one coil pair at the driver.

The motor mounts to the printed pump housing with M3×16 mm screws; mechanical
assembly follows [Puschmann’s documentation](HARDWARE.md).

## Control signal diagram

```mermaid
flowchart TB
  subgraph esp [ESP32]
    STEP["GPIO 26 STEP"]
    DIR["GPIO 27 DIR"]
    EN["GPIO 25 ENABLE<br/>active low"]
    TX["GPIO 17 TX optional"]
    RX["GPIO 16 RX optional"]
    VALVE["GPIO 33 VALVE optional"]
    ESTOP["GPIO 32 ESTOP optional"]
    RES["GPIO 34 RESERVOIR optional"]
  end

  subgraph tmc [TMC2209]
    TSTEP["STEP"]
    TDIR["DIR"]
    TEN["EN"]
    TUART["PDN_UART"]
    COILS["A1 A2 B1 B2"]
  end

  subgraph extras [Optional]
    VDRV["Valve driver"]
    SW["ESTOP NO → GND"]
    FLOAT["Empty switch + 10 kΩ pull-up"]
  end

  STEP --> TSTEP
  DIR --> TDIR
  EN --> TEN
  TX --> TUART
  RX --> TUART
  VALVE --> VDRV
  ESTOP --> SW
  RES --> FLOAT
  COILS --> MOTOR["NEMA 17"]
```

## Optional connections

### TMC2209 UART

| ESP32 | TMC2209 | Notes |
|---|---|---|
| GPIO **17** (`TX`) | `PDN_UART` | Configure current / microsteps / StealthChop |
| GPIO **16** (`RX`) | UART return / PDN sense per silkscreen | Single-wire UART path on many StepSticks |

Enable motor-driver UART in Configuration after wiring. Motion still uses STEP/DIR;
UART only configures the driver. See [HARDWARE.md](HARDWARE.md).

### Valve (anti-drip / cutoff)

| ESP32 | Device | Notes |
|---|---|---|
| GPIO **33** | Valve **driver** enable/input | Active-high in firmware by default |
| Valve driver power | Per valve datasheet | Often not 3.3 V logic-level coil drive |
| Valve ports | Fluid line after pump | Chemically compatible, normally closed preferred |

Mark the matching pump as having a shutoff valve in Configuration before use.

### Emergency stop

| ESP32 | Switch |
|---|---|
| GPIO **32** | One side of NO ESTOP |
| `GND` | Other side of NO ESTOP |

Active-low with internal pull-up. Enable in Configuration before relying on it.

### Reservoir empty sense

| Connection | Notes |
|---|---|
| GPIO **34** | Input-only; **no** internal pull-up |
| 10 kΩ to `3V3` | External pull-up |
| NO float/optical switch to `GND` | Asserts empty when closed (default active-low) |

### Stepper driver control — pump 2 / pump 3 (optional)

Set **Number of installed pumps = 2 or 3** in Configuration. Strap each extra TMC2209 UART
address via MS1/MS2 (`0b01` for pump 2, `0b10` for pump 3).

| ESP32 GPIO | Signal | Notes |
|---|---|---|
| **5** | Pump 2 `STEP` | |
| **13** | Pump 2 `DIR` | |
| **14** | Pump 2 `EN` | Active low |
| **21** | Pump 2 valve driver (optional) | Driver only — not piezo coils |
| **22** | Pump 3 `STEP` | |
| **15** | Pump 3 `DIR` | Strapping pin — quiet at boot |
| **2** | Pump 3 `EN` | Active low |
| **12** | Pump 3 valve driver (optional) | Strapping pin — quiet at boot |
| 16 / 17 | Shared UART RX/TX | Addresses `0b00` / `0b01` / `0b10` |

## Pin summary

| Function | GPIO | Required | Polarity / notes |
|---|---|---|---|
| Pump 1 STEP | 26 | Yes | Pulse to TMC #1 |
| Pump 1 DIR | 27 | Yes | Level to TMC #1 |
| Pump 1 ENABLE | 25 | Yes | Active low |
| Pump 1 VALVE | 33 | No | To valve driver only |
| Pump 2 STEP | 5 | No | Configuration pump count ≥ 2 |
| Pump 2 DIR | 13 | No | |
| Pump 2 ENABLE | 14 | No | Active low |
| Pump 2 VALVE | 21 | No | To valve driver only |
| Pump 3 STEP | 22 | No | Configuration pump count ≥ 3 |
| Pump 3 DIR | 15 | No | Strapping |
| Pump 3 ENABLE | 2 | No | Active low |
| Pump 3 VALVE | 12 | No | Strapping; valve driver only |
| ESTOP | 32 | No | Active low to GND |
| TMC RX | 16 | No | UART (shared, up to 4 addresses) |
| TMC TX | 17 | No | UART |
| RESERVOIR | 34 | No | External pull-up required |
| HX711 DT | 19 | No | |
| HX711 SCK | 18 | No | |
| TEMP | 23 | No | DS18B20 1-Wire |
| FLOW | 4 | No | Pulse input |

**Motion limit:** firmware runs **one path at a time** (no concurrent STEP). Size
the 12 V supply for a single 1.5 A/phase motor unless you validate multi-load.

## Common mistakes

| Mistake | Result |
|---|---|
| No common ground | Erratic STEP/DIR, UART failures |
| 12 V into ESP32 `VIN` | Damaged board |
| Cap far from `VMOT` | Driver resets / noise under load |
| Piezo valve on GPIO 33 | Damaged ESP32 / non-functional valve |
| ENABLE assumed active-high | Motor always on or never enables |
| Forgetting `upload` vs USB-only power | Weak 5 V from USB while motor draws from 12 V — use the buck for sustained runs |

## Plumbing (not electrical)

Fluid contacts **tubing only** inside the peristaltic pump. Keep reservoirs,
tubing, and any valve physically separated from the ESP32, driver, and buck
converter. Dedicate tubing per fluid when cross-contamination matters.

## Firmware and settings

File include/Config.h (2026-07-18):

#pragma once

#include <Arduino.h>

// Compile-time pin defaults (overridable via platformio.ini build_flags).
#ifndef PUMP_STEP_PIN
#define PUMP_STEP_PIN 26
#endif
#ifndef PUMP_DIR_PIN
#define PUMP_DIR_PIN 27
#endif
#ifndef PUMP_ENABLE_PIN
#define PUMP_ENABLE_PIN 25
#endif
#ifndef PUMP_VALVE_PIN
#define PUMP_VALVE_PIN 33
#endif
#ifndef PUMP_ESTOP_PIN
#define PUMP_ESTOP_PIN 32
#endif
#ifndef PUMP_TMC_RX_PIN
#define PUMP_TMC_RX_PIN 16
#endif
#ifndef PUMP_TMC_TX_PIN
#define PUMP_TMC_TX_PIN 17
#endif
#ifndef PUMP_RESERVOIR_PIN
#define PUMP_RESERVOIR_PIN 34
#endif
#ifndef PUMP_LOADCELL_DT_PIN
#define PUMP_LOADCELL_DT_PIN 19
#endif
#ifndef PUMP_LOADCELL_SCK_PIN
#define PUMP_LOADCELL_SCK_PIN 18
#endif
#ifndef PUMP_TEMP_PIN
#define PUMP_TEMP_PIN 23
#endif
#ifndef PUMP_FLOW_PIN
#define PUMP_FLOW_PIN 4
#endif

// Optional second fluid path (enabled when GlobalSettings.pumpCount >= 2).
#ifndef PUMP2_STEP_PIN
#define PUMP2_STEP_PIN 5
#endif
#ifndef PUMP2_DIR_PIN
#define PUMP2_DIR_PIN 13
#endif
#ifndef PUMP2_ENABLE_PIN
#define PUMP2_ENABLE_PIN 14
#endif
#ifndef PUMP2_VALVE_PIN
#define PUMP2_VALVE_PIN 21
#endif
#ifndef PUMP2_TMC_ADDRESS
#define PUMP2_TMC_ADDRESS 0b01
#endif

// Optional third fluid path (enabled when GlobalSettings.pumpCount >= 3).
#ifndef PUMP3_STEP_PIN
#define PUMP3_STEP_PIN 22
#endif
#ifndef PUMP3_DIR_PIN
#define PUMP3_DIR_PIN 15
#endif
#ifndef PUMP3_ENABLE_PIN
#define PUMP3_ENABLE_PIN 2
#endif
#ifndef PUMP3_VALVE_PIN
#define PUMP3_VALVE_PIN 12
#endif
#ifndef PUMP3_TMC_ADDRESS
#define PUMP3_TMC_ADDRESS 0b10
#endif

namespace Config {
constexpr const char* kDeviceName = "Fluid Dispensing Controller";
constexpr const char* kHostname = "pump-controller";
constexpr const char* kApSsid = "PumpController";
constexpr const char* kApPassword = "pumpsetup";
constexpr uint32_t kDefaultSpeedStepsPerSec = 1600;
constexpr uint32_t kDefaultAccelStepsPerSec2 = 800;
constexpr uint32_t kMinSpeedStepsPerSec = 100;
constexpr uint32_t kMaxSpeedStepsPerSec = 5000;
constexpr uint32_t kMinAccelStepsPerSec2 = 100;
constexpr uint32_t kMaxAccelStepsPerSec2 = 20000;
constexpr uint32_t kDefaultCalibrationDurationMs = 1000;
constexpr int64_t kMaxOperationSteps = 5000000;
constexpr float kDefaultMinDispenseMl = 1.0f;
constexpr float kDefaultMaxDispenseMl = 1000.0f;
constexpr uint32_t kDriverDisableDelayMs = 500;
constexpr float kCalibrationCvWarningPercent = 3.0f;
constexpr int kProfilesSchemaVersion = 2;
constexpr uint32_t kMaxValveTimingMs = 5000;
constexpr uint16_t kDefaultTmcRunCurrentMa = 800;
constexpr uint16_t kDefaultTmcHoldCurrentMa = 400;
constexpr uint16_t kDefaultTmcMicrosteps = 16;
constexpr float kDefaultLoadCellScale = 1.0f;
constexpr float kDefaultFluidDensityGPerMl = 1.0f;
constexpr float kDefaultTempWarnLowC = 5.0f;
constexpr float kDefaultTempWarnHighC = 40.0f;
constexpr float kDefaultFlowPulsesPerLiter = 450.0f;
constexpr uint8_t kMaxPumpCount = 3;
constexpr uint8_t kDefaultPumpCount = 1;
}  // namespace Config

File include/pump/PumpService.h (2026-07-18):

#pragma once

#include <Arduino.h>
#include <vector>

#include "diagnostics/EventLogger.h"
#include "models/FluidProfile.h"
#include "models/OperationStatus.h"
#include "models/PumpInstance.h"
#include "motor/StepperController.h"
#include "motor/TmcDriverController.h"
#include "safety/SafetyController.h"
#include "sensors/FlowSensor.h"
#include "sensors/LoadCellSensor.h"
#include "sensors/ReservoirSensor.h"
#include "storage/ProfileRepository.h"
#include "valve/ValveController.h"

struct CalibrationSample {
    uint32_t requestedDurationMs = 0;
    uint32_t actualDurationMs = 0;
    int64_t stepCount = 0;
    float measuredMl = 0.0f;
    uint64_t timestamp = 0;
};

struct CalibrationResult {
    bool valid = false;
    float stepsPerMl = 0.0f;
    float mlPerSecond = 0.0f;
    float sampleAverageMl = 0.0f;
    float sampleStdDevMl = 0.0f;
    float coefficientOfVariation = 0.0f;
    uint8_t sampleCount = 0;
};

enum class ReservoirEmptyPolicy : uint8_t {
    Warn,
    Block,
    Fault
};

enum class DispenseFeedbackMode : uint8_t {
    OpenLoop,
    VerifyAfter,
    StopOnFeedback
};

enum class DispenseFeedbackSource : uint8_t {
    Auto,
    LoadCell,
    Flow
};

enum class DispenseFeedbackOnMiss : uint8_t {
    Warn,
    Fault
};

inline ReservoirEmptyPolicy parseReservoirEmptyPolicy(const String& value) {
    if (value == "warn") {
        return ReservoirEmptyPolicy::Warn;
    }
    if (value == "fault") {
        return ReservoirEmptyPolicy::Fault;
    }
    return ReservoirEmptyPolicy::Block;
}

inline const char* reservoirEmptyPolicyToString(ReservoirEmptyPolicy policy) {
    switch (policy) {
        case ReservoirEmptyPolicy::Warn: return "warn";
        case ReservoirEmptyPolicy::Fault: return "fault";
        case ReservoirEmptyPolicy::Block:
        default:
            return "block";
    }
}

inline DispenseFeedbackMode parseDispenseFeedbackMode(const String& value) {
    if (value == "verify_after") {
        return DispenseFeedbackMode::VerifyAfter;
    }
    if (value == "stop_on_feedback") {
        return DispenseFeedbackMode::StopOnFeedback;
    }
    return DispenseFeedbackMode::OpenLoop;
}

inline const char* dispenseFeedbackModeToString(DispenseFeedbackMode mode) {
    switch (mode) {
        case DispenseFeedbackMode::VerifyAfter: return "verify_after";
        case DispenseFeedbackMode::StopOnFeedback: return "stop_on_feedback";
        case DispenseFeedbackMode::OpenLoop:
        default:
            return "open_loop";
    }
}

inline DispenseFeedbackSource parseDispenseFeedbackSource(const String& value) {
    if (value == "load_cell") {
        return DispenseFeedbackSource::LoadCell;
    }
    if (value == "flow") {
        return DispenseFeedbackSource::Flow;
    }
    return DispenseFeedbackSource::Auto;
}

inline const char* dispenseFeedbackSourceToString(DispenseFeedbackSource source) {
    switch (source) {
        case DispenseFeedbackSource::LoadCell: return "load_cell";
        case DispenseFeedbackSource::Flow: return "flow";
        case DispenseFeedbackSource::Auto:
        default:
            return "auto";
    }
}

inline DispenseFeedbackOnMiss parseDispenseFeedbackOnMiss(const String& value) {
    if (value == "fault") {
        return DispenseFeedbackOnMiss::Fault;
    }
    return DispenseFeedbackOnMiss::Warn;
}

inline const char* dispenseFeedbackOnMissToString(DispenseFeedbackOnMiss value) {
    switch (value) {
        case DispenseFeedbackOnMiss::Fault: return "fault";
        case DispenseFeedbackOnMiss::Warn:
        default:
            return "warn";
    }
}

class PumpService {
public:
    void begin(
        StepperController& stepper,
        ValveController& valve,
        ProfileRepository& profiles,
        SafetyController& safety,
        EventLogger& logger,
        TmcDriverController& tmc,
        ReservoirSensor& reservoir,
        LoadCellSensor& loadCell,
        FlowSensor& flow
    );
    /** Register optional additional path hardware (pins begun by caller). */
    void configureSecondPath(StepperController& stepper, ValveController& valve);
    void configureThirdPath(StepperController& stepper, ValveController& valve);
    void setPumpCount(uint8_t count);
    void applyValveHardware(
        bool pump1Present,
        bool pump2Present,
        bool pump3Present
    );

    void update();
    void setReservoirEmptyPolicy(ReservoirEmptyPolicy policy);
    void setFeedbackConfig(
        DispenseFeedbackMode mode,
        DispenseFeedbackSource source,
        float tolerancePercent,
        DispenseFeedbackOnMiss onMiss,
        float densityGPerMl
    );

    bool startDispense(const DispenseRequest& request);
    bool startCalibration(const String& profileId, uint32_t durationMs);
    void requestStop();
    bool acknowledgeFault();
    bool injectMotorDriverFault();

    bool submitCalibrationMeasurement(float measuredMl);
    bool removeCalibrationSample(size_t index);
    bool saveCalibration();
    void discardPendingCalibration();
    CalibrationResult calculateCalibrationResult() const;
    const std::vector<CalibrationSample>& pendingSamples() const {
        return samples_;
    }

    SystemState state() const { return state_; }
    OperationStatus getProgress() const;
    bool isBusy() const;
    FaultCode lastFault() const { return lastFault_; }
    const String& activeOperationId() const { return operationId_; }
    const String& activePumpId() const { return activePumpId_; }
    uint8_t pumpCount() const { return static_cast<uint8_t>(pathCount_); }
    bool anyMotorRunning() const;
    bool anyValveOpen() const;
    ReservoirEmptyPolicy reservoirEmptyPolicy() const {
        return reservoirPolicy_;
    }
    bool reservoirEmptyWarning() const { return reservoirEmptyWarning_; }
    DispenseFeedbackMode feedbackMode() const { return feedbackMode_; }
    DispenseFeedbackSource feedbackSource() const { return feedbackSource_; }
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

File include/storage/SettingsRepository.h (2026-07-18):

#pragma once

#include <Arduino.h>

struct GlobalSettings {
    String deviceName = "Fluid Dispensing Controller";
    String hostname = "pump-controller";
    String wifiMode = "ap";  // ap | station
    bool emergencyStopEnabled = false;
    bool driverUartEnabled = false;
    uint16_t driverRunCurrentMa = 800;
    uint16_t driverHoldCurrentMa = 400;
    uint16_t driverMicrosteps = 16;
    bool driverStealthChop = true;
    bool loggingEnabled = true;
    bool webAuthEnabled = false;
    bool valveHardwarePresent = false;
    /** 1 = single path (default). 2 = enable second STEP/DIR/EN path. */
    uint8_t pumpCount = 1;
    bool pump2ValveHardwarePresent = false;
    bool pump3ValveHardwarePresent = false;
    bool reservoirSensorEnabled = false;
    bool reservoirEmptyActiveLow = true;
    // warn | block | fault
    String reservoirEmptyPolicy = "block";
    bool loadCellEnabled = false;
    float loadCellScale = 1.0f;
    int32_t loadCellOffset = 0;
    float fluidDensityGPerMl = 1.0f;
    bool temperatureSensorEnabled = false;
    float temperatureWarnLowC = 5.0f;
    float temperatureWarnHighC = 40.0f;
    bool flowSensorEnabled = false;
    float flowPulsesPerLiter = 450.0f;
    // open_loop | verify_after | stop_on_feedback
    String dispenseFeedbackMode = "open_loop";
    // auto | load_cell | flow
    String dispenseFeedbackSource = "auto";
    float dispenseFeedbackTolerancePercent = 5.0f;
    // warn | fault
    String dispenseFeedbackOnMiss = "warn";
};

class SettingsRepository {
public:
    bool begin();
    GlobalSettings get() const { return settings_; }
    bool save(const GlobalSettings& settings);
    /** Clear NVS settings namespace and restore in-memory defaults. */
    bool factoryResetSettings();

private:
    GlobalSettings settings_;
    void loadDefaults();
};

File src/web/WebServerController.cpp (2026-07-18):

#include "web/WebServerController.h"

#include <ArduinoJson.h>
#include <LittleFS.h>
#include <WiFi.h>
#include <cmath>

#include "Config.h"
#include "secrets.h"

namespace {

void sendJson(AsyncWebServerRequest* request, int status, const JsonDocument& doc) {
    String payload;
    serializeJson(doc, payload);
    request->send(status, "application/json", payload);
}

void sendError(AsyncWebServerRequest* request, int status, const char* message) {
    JsonDocument doc;
    doc["error"] = message;
    sendJson(request, status, doc);
}

bool readJsonBody(uint8_t* data, size_t len, JsonDocument& doc) {
    if (data == nullptr || len == 0) {
        return false;
    }
    return deserializeJson(doc, data, len) == DeserializationError::Ok;
}

bool clampMotorSettings(MotorSettings& motor) {
    if (motor.speedStepsPerSecond < Config::kMinSpeedStepsPerSec ||
        motor.speedStepsPerSecond > Config::kMaxSpeedStepsPerSec) {
        return false;
    }
    if (motor.accelerationStepsPerSecondSquared < Config::kMinAccelStepsPerSec2 ||
        motor.accelerationStepsPerSecondSquared > Config::kMaxAccelStepsPerSec2) {
        return false;
    }
    if (motor.decelerationStepsPerSecondSquared < Config::kMinAccelStepsPerSec2 ||
        motor.decelerationStepsPerSecondSquared > Config::kMaxAccelStepsPerSec2) {
        return false;
    }
    return true;
}

bool clampTmcSettings(const GlobalSettings& settings) {
    if (settings.driverRunCurrentMa < 100 || settings.driverRunCurrentMa > 2000) {
        return false;
    }
    if (settings.driverHoldCurrentMa > settings.driverRunCurrentMa) {
        return false;
    }
    switch (settings.driverMicrosteps) {
        case 1:
        case 2:
        case 4:
        case 8:
        case 16:
        case 32:
        case 64:
        case 128:
        case 256:
            return true;
        default:
            return false;
    }
}

bool clampValveSettings(const ValveSettings& valve) {
    if (valve.preOpenMs > Config::kMaxValveTimingMs ||
        valve.postMotorCloseMs > Config::kMaxValveTimingMs) {
        return false;
    }
    if (valve.antiDripReverseSteps < 0 || valve.antiDripReverseSteps > 5000) {
        return false;
    }
    if (valve.antiDripEnabled &&
        (valve.antiDripSpeedStepsPerSecond < Config::kMinSpeedStepsPerSec ||
         valve.antiDripSpeedStepsPerSecond > Config::kMaxSpeedStepsPerSec)) {
        return false;
    }
    return true;
}

}  // namespace

bool WebServerController::requireAuth(AsyncWebServerRequest* request) const {
    if (settings_ == nullptr || !settings_->get().webAuthEnabled) {
        return true;
    }
    if (request->authenticate(Secrets::kWebUsername, Secrets::kWebPassword)) {
        return true;
    }
    request->requestAuthentication("PumpController");
    return false;
}

void WebServerController::fillProfileJson(
    const FluidProfile& profile,
    JsonObject doc
) const {
    doc["id"] = profile.id;
    doc["name"] = profile.name;
    doc["pump_id"] = profile.pumpId;
    doc["enabled"] = profile.enabled;
    doc["calibrated"] = profile.calibrated;

    JsonObject cal = doc["calibration"].to<JsonObject>();
    cal["method"] = profile.calibration.method;
    cal["requested_duration_ms"] = profile.calibration.requestedDurationMs;
    cal["actual_duration_ms"] = profile.calibration.actualDurationMs;
    cal["step_count"] = profile.calibration.stepCount;
    cal["measured_ml"] = profile.calibration.measuredMl;
    cal["steps_per_ml"] = profile.calibration.stepsPerMl;
    cal["ml_per_second"] = profile.calibration.mlPerSecond;
    cal["sample_count"] = profile.calibration.sampleCount;
    cal["calibrated_at"] = profile.calibration.calibratedAt;

    JsonObject motor = doc["motor"].to<JsonObject>();
    motor["speed_steps_per_second"] = profile.motor.speedStepsPerSecond;
    motor["acceleration_steps_per_second_squared"] =
        profile.motor.accelerationStepsPerSecondSquared;
    motor["deceleration_steps_per_second_squared"] =
        profile.motor.decelerationStepsPerSecondSquared;
    motor["direction_inverted"] = profile.motor.directionInverted;
    motor["microsteps"] = profile.motor.microsteps;

    JsonObject valve = doc["valve"].to<JsonObject>();
    valve["enabled"] = profile.valve.enabled;
    valve["active_high"] = profile.valve.activeHigh;
    valve["pre_open_ms"] = profile.valve.preOpenMs;
    valve["post_motor_close_ms"] = profile.valve.postMotorCloseMs;
    valve["anti_drip_enabled"] = profile.valve.antiDripEnabled;
    valve["anti_drip_reverse_steps"] = profile.valve.antiDripReverseSteps;
    valve["anti_drip_speed_steps_per_second"] =
        profile.valve.antiDripSpeedStepsPerSecond;

    JsonObject limits = doc["limits"].to<JsonObject>();
    limits["minimum_ml"] = profile.limits.minimumMl;
    limits["maximum_ml"] = profile.limits.maximumMl;
}

void WebServerController::fillTmcSettingsJson(
    const GlobalSettings& settings,
    JsonObject doc
) const {
    doc["driver_uart_enabled"] = settings.driverUartEnabled;
    doc["driver_run_current_ma"] = settings.driverRunCurrentMa;
    doc["driver_hold_current_ma"] = settings.driverHoldCurrentMa;
    doc["driver_microsteps"] = settings.driverMicrosteps;
    doc["driver_stealthchop"] = settings.driverStealthChop;
}

bool WebServerController::applyTmcFromBody(
    JsonObjectConst body,
    GlobalSettings& settings
) const {
    settings.driverUartEnabled =
        body["driver_uart_enabled"] | settings.driverUartEnabled;
    settings.driverRunCurrentMa =
        body["driver_run_current_ma"] | settings.driverRunCurrentMa;
    settings.driverHoldCurrentMa =
        body["driver_hold_current_ma"] | settings.driverHoldCurrentMa;
    settings.driverMicrosteps =
        body["driver_microsteps"] | settings.driverMicrosteps;
    settings.driverStealthChop =
        body["driver_stealthchop"] | settings.driverStealthChop;
    return clampTmcSettings(settings);
}

void WebServerController::fillReservoirSettingsJson(
    const GlobalSettings& settings,
    JsonObject doc
) const {
    doc["reservoir_sensor_enabled"] = settings.reservoirSensorEnabled;
    doc["reservoir_empty_active_low"] = settings.reservoirEmptyActiveLow;
    doc["reservoir_empty_policy"] = settings.reservoirEmptyPolicy;
}

bool WebServerController::applyReservoirFromBody(
    JsonObjectConst body,
    GlobalSettings& settings
) const {
    settings.reservoirSensorEnabled =
        body["reservoir_sensor_enabled"] | settings.reservoirSensorEnabled;
    settings.reservoirEmptyActiveLow =
        body["reservoir_empty_active_low"] | settings.reservoirEmptyActiveLow;
    const char* policy =
        body["reservoir_empty_policy"] | settings.reservoirEmptyPolicy.c_str();
    const String policyStr = policy;
    if (policyStr != "warn" && policyStr != "block" && policyStr != "fault") {
        return false;
    }
    settings.reservoirEmptyPolicy = policyStr;
    return true;
}
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

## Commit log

2026-07-18 Initial public release of Precision Pump Controller.
    Open-source ESP32 firmware and web UI for generic precision fluid dispensing, with BOM, MIT license, and primary hardware credit to Maximilian Puschmann's NEMA 17 peristaltic pump design.
2026-07-18 Make fluid profiles and branding use-case agnostic.
    Replace domain-specific defaults with Fluid 1–6 and rename the product to Fluid Dispensing Controller so the same firmware fits hydroponics, laundry, lab dosing, and similar work. Add CONTRIBUTING.md for scoped follow-on work.
    Closes #1
    [ApplicationController.cpp, Config.h, FluidProfile.h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]
2026-07-18 Add non-blocking valve pre-open and post-close sequencing.
    Honors profile valve timing around dispense and calibration without delay() in the control loop, closes immediately on stop/fault, and no-ops when valve hardware is absent.
    Closes #2
2026-07-18 Expose full valve timing settings in Profiles UI and API.
    Persist enabled/active-high/pre-open/post-close with range checks, surface valve hardware toggle in Diagnostics, and re-init the valve controller when that setting changes.
    Closes #3
2026-07-18 Add anti-drip reverse after dispense and calibration.
    Runs optional reverse steps before valve post-close, exposes settings in Profiles UI/API, and clears calibration when anti-drip parameters change.
    Closes #4
    [PumpService.cpp, PumpService.h, WebServerController.cpp]
2026-07-18 Enable and document physical ESTOP as a first-class safety path.
    Expose ESTOP enable/live state in Diagnostics and status API, log activate/ack events, re-init SafetyController from settings, and document GPIO 32 wiring in HARDWARE/BOM.
    Closes #5
2026-07-18 Add optional TMC2209 UART current and microstep configuration.
    Keeps STEP/DIR motion primary and fails soft when UART is missing or miswired.
    Closes #6
    [ApplicationController.cpp, Config.h, SettingsRepository.cpp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]
2026-07-18 Poll TMC2209 diagnostics and raise motor driver faults.
    Surfaces OT/short/open-load in status, stops motion safely, and supports simulated faults for acceptance without hardware.
    Closes #7
    [ApplicationController.cpp, PumpService.cpp, PumpService.h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]
2026-07-18 Add optional reservoir empty sensor with warn/block/fault policy.
    GPIO 34 input surfaces empty state in status/UI and can refuse or fault dispense.
    Closes #8
2026-07-18 Update documentation and .gitignore for wiring and enclosure details
    - Added wiring information to README and HARDWARE.md.
    - Updated project layout in README to include wiring and enclosure details.
    - Enhanced .gitignore to exclude __pycache__ directories in the cad folder.
    [assembly_1pump.step, assembly_2pump.step, assembly_3pump.step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]
2026-07-18 Add optional HX711 load-cell reading with tare and scale calibration.
    Surfaces grams (and density-based mL) in status/Diagnostics without changing open-loop dispense.
    Closes #17
2026-07-18 Add optional DS18B20 temperature sensing with warn thresholds.
    Live °C on status/Diagnostics; threshold crossings log warnings without faulting dispense.
    Closes #18
2026-07-18 Add optional pulse flow sensor with rate and cumulative volume.
    GPIO 4 interrupt counting with configurable pulses/liter; does not change open-loop dispense.
    Closes #19
2026-07-18 Update README and remove unused STEP files
    - Updated README to clarify the location of dry-side enclosure STEP files, including links to specific versions.
    - Deleted multiple unused STEP files for 1 to 6 pump assemblies and the controller base to streamline the repository.
    [assembly_1pump.step, assembly_2pump.step, assembly_3pump.step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]
2026-07-18 Add optional closed-loop dispense feedback via load cell or flow.
    Supports open-loop, verify-after, and stop-on-feedback with tolerance warn/fault policy.
    Closes #20
    [ApplicationController.cpp, PumpService.cpp, PumpService.h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]
2026-07-18 Add support for configurable dispense feedback options
    Enhance the dispensing functionality by allowing users to configure feedback options, including load cell and flow sensor integration. This update maintains compatibility with existing open-loop disp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
2026-07-18 Add optional second pump path with profile binding. (#30)
    Introduce PumpPath binding so FluidProfiles target pump_1 or pump_2.
    Default pump_count=1 preserves single-path behavior; with count=2 the
    second STEP/DIR/EN (GPIO 5/13/14) and optional valve (21) are active.
    Motion remains sequential (one busy path) to avoid crosstalk. Document
    pin budget and TMC UART address 0b01 for the second driver.
    Closes #21
    [ApplicationController.cpp, Config.h, FluidProfile.h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]
2026-07-18 Persist profiles and calibration in NVS across upgrades (#32)
    Move fluid profiles and calibration from LittleFS into Preferences NVS
    (pump_prof) so values survive upload and uploadfs. Hardware settings
    remain in pump_settings. Migrate existing profiles.json once, stop
    auto-formatting LittleFS on mount failure, and add an explicit Factory
    Reset API/UI that clears NVS only on confirmed user action.
    Closes #31
    [ApplicationController.cpp, ProfileRepository.cpp, ProfileRepository.h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]
2026-07-18 Add third pump path (pump_count up to 3) (#34)
    Extend multi-pump support with pump_3 on STEP/DIR/EN GPIO 22/15/2,
    optional valve GPIO 12, and TMC UART address 0b10 on the shared bus.
    Diagnostics, Profiles, Hardware UI, and docs updated. Default remains
    single-path; motion stays sequential.
    Closes #33
2026-07-18 Document multi-pump support and require docs with product changes (#36)
    Refresh README pin tables and enablement steps for pump_1–3, expand
    DESIGN/BOM/docs index for multi-pump builds, and add an always-apply
    Cursor rule plus CONTRIBUTING checklist so documentation stays in sync.
    Closes #35
2026-07-18 Separate configuration from live diagnostics (#38)
    Replace the engineering-first settings page with outcome-oriented setup,
    progressive disclosure, and clear effect summaries. Keep diagnostics focused
    on live health, fault controls, and event history so routine setup and
    troubleshooting have distinct workflows.
    Closes #37
    [configuration.js]
2026-07-18 Add dynamic color-coded wiring diagram modal (#40)
    Show an SVG wiring diagram from Hardware and Configuration that reflects
    the active pump count and enabled valves, UART, ESTOP, and sensors so
    users can verify connections without leaving the web UI.
    Closes #39
2026-07-18 Remove obsolete controller_base.stl file from the enclosure v2 directory
    [controller_base.stl]
2026-07-20 Wiring diagram: show power and ground connections (#42)
    * Show power and ground in wiring diagram
    Add 12 V and GND rails, VMOT/GND drops to each driver, buck-derived 5 V to
    the ESP32, ESP32 3.3 V logic to each driver, and label motor phase wiring so
    the diagram documents power distribution, not just control signals.
    Closes #41
    * Label motor 4-wire connector and per-component power
    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
